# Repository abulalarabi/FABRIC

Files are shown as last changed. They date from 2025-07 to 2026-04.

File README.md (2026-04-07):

# **FABRIC**: `FA`bricating `B`odily-Expressive `R`obots for `I`nclusive and Low-`C`ost Design

## Abstract
Sign language is a vital visual-manual communication method for individuals with hearing impairments, yet current robotic systems remain expensive and technically inaccessible for embodied interaction. We present **FABRIC**, a low-cost, end-to-end toolkit that enables users to 3D print expressive robots and program bodily language through learning-from-demonstration. FABRIC supports upper-torso motion replication using video input and offers an intuitive visual programming interface, lowering barriers to designing embodied, communicative robots for diverse applications.

<p align="center">
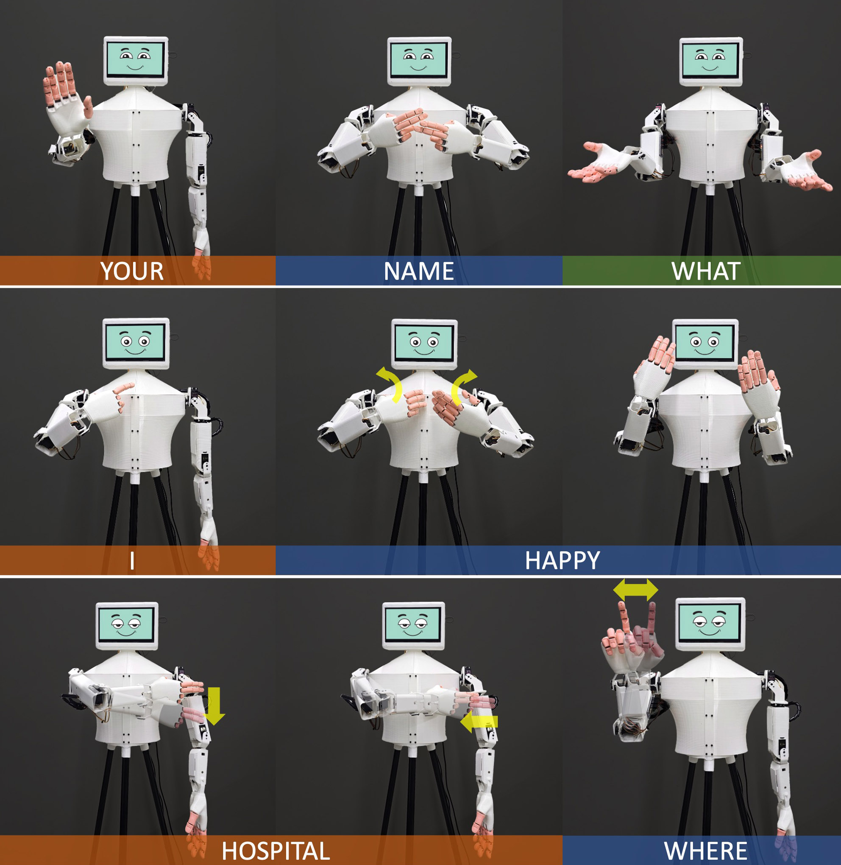
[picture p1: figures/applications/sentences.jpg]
  
</p>

## Paper Citation
```
@INPROCEEDINGS{11247443,
  author={Arabi, Abul Al and Kim, Jeeeun},
  booktitle={2025 IEEE/RSJ International Conference on Intelligent Robots and Systems (IROS)}, 
  title={FABRIC: FAbricating Bodily-Expressive Robots for Inclusive and Low-Cost Design}, 
  year={2025},
  volume={},
  number={},
  pages={1139-1146},
  keywords={Humanoid robot, Sign language robot, 3D Printing, Pose Estimation, Learningfromdemonstration},
  doi={10.1109/IROS60139.2025.11247443}}
```

## System Overview

<p align="center">
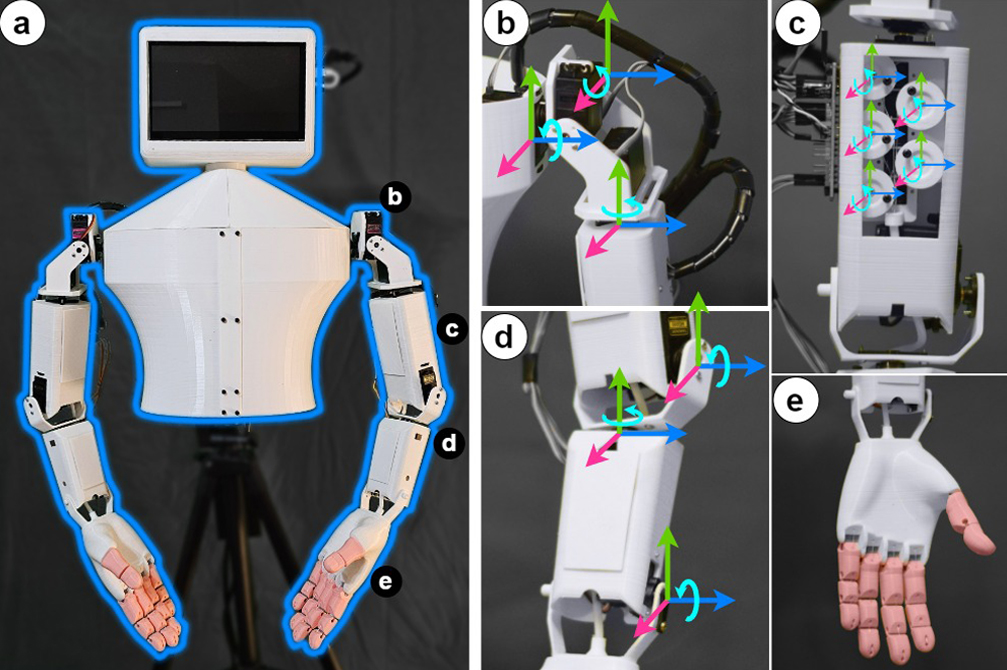
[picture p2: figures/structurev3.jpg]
  
</p>

Components of the FABRIC robot:  
(a) Assembled FABRIC unit  
(b) Shoulder joints  
(c) Finger movement servos mounted inside the upper arm  
(d) Elbow and wrist joint  
(e) Robotic hand

## Design Files
<table>
  <tr>
    <td align="center">
      <a href="design_files/body">
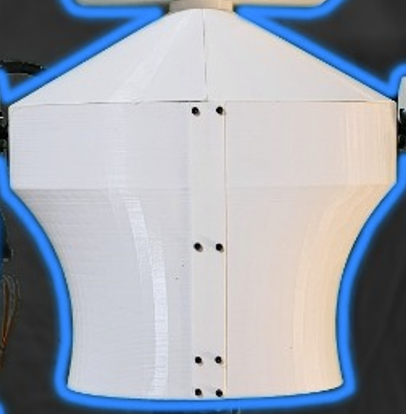
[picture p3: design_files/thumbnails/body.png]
        <br/>
        <sub><b>Body</b></sub>
      </a>
    </td>
    <td align="center">
      <a href="design_files/elbow">
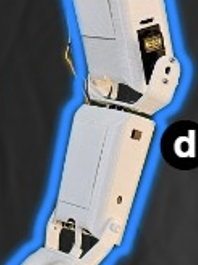
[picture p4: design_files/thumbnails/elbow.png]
        <br/>
        <sub><b>Elbow</b></sub>
      </a>
    </td>
    <td align="center">
      <a href="design_files/head">
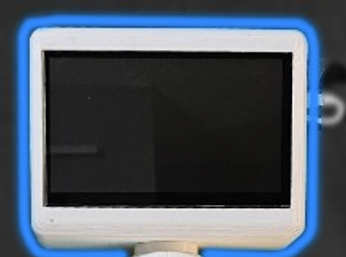
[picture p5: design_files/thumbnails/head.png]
        <br/>
        <sub><b>Head</b></sub>
      </a>
    </td>
    <td align="center">
      <a href="design_files/shoulder">
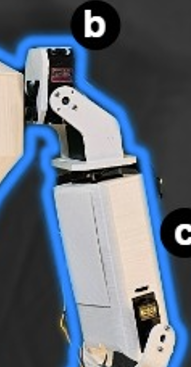
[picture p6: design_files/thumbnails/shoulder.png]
        <br/>
        <sub><b>Shoulder</b></sub>
      </a>
    </td>
  </tr>
  <tr>
    <td align="center">
      <a href="design_files/wrist+hand">
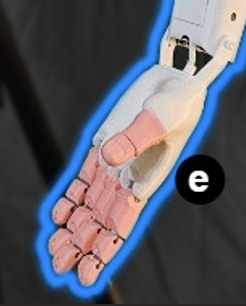
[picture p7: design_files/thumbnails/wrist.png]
        <br/>
        <sub><b>Wrist + Hand</b></sub>
      </a>
    </td>
    <td align="center">
      <a href="design_files/rivets">
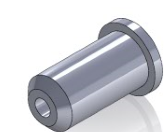
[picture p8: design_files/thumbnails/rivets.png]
        <br/>
        <sub><b>Rivets</b></sub>
      </a>
    </td>
    <td align="center">
      <a href="design_files/stand">
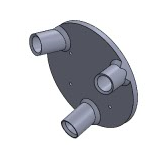
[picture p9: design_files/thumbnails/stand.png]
        <br/>
        <sub><b>Stand</b></sub>
      </a>
    </td>
    <td></td>
  </tr>
</table>

## Firmware
<a href="firmware">
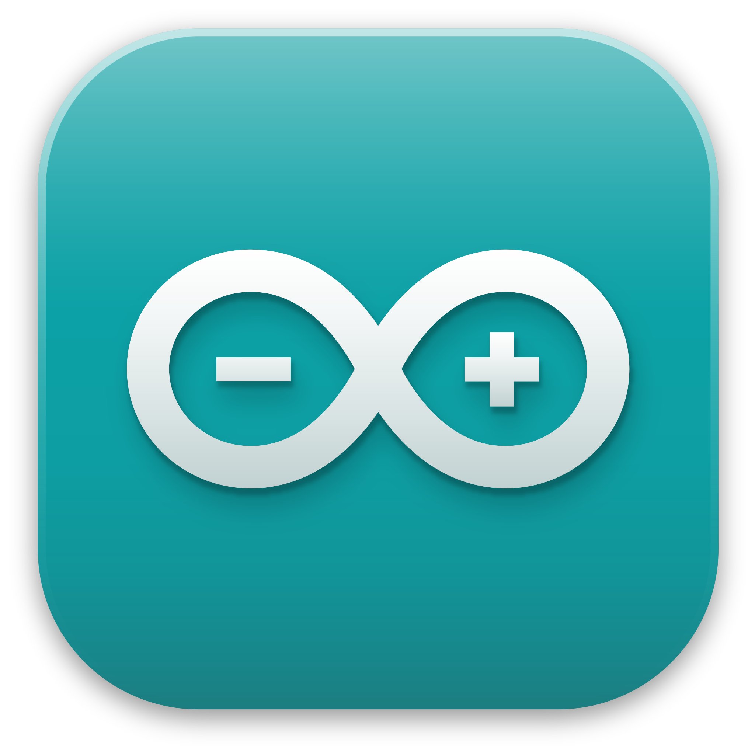
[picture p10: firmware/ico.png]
  <br/>
  <sub><b>Arduino Firmware of ESP32 (UART Version)</b></sub>
</a>

## Frontend + Backend
Will be updated soon.

## BoM and Component List

| Component | Quantity | URL |
|---|---|-----|
| ESP32 microcontroller | 1 | [Link](https://www.amazon.com/s?k=ESP32+microcontroller) |
| PCA9685 Servo Driver | 2 | [Link](https://www.amazon.com/s?k=PCA9685+Servo+Driver+module) |
| LM2596S DC-DC Converter | 1 | [Link](https://www.amazon.com/s?k=LM2596S+DC-DC+Converter) |
| MG996R Servos (arm) | 8 | [Link](https://www.amazon.com/s?k=MG996R+servo+motor) |
| SG90 Servos (finger/wrist) | 14 | [Link](https://www.amazon.com/s?k=SG90+mini+servo+motor) |
| PLA Filament (~1.5 kg) | ~1.5 kg | [Link](https://www.amazon.com/s?k=PLA+1.75mm+3D+printer+filament) |
| TPU Filament (~0.25 kg) | ~0.25 kg | [Link](https://www.amazon.com/s?k=TPU+1.75mm+flexible+filament) |
| PTFE Tube | 1 meter | [Link](https://www.amazon.com/s?k=PTFE+tube+1.75mm) |
| Power Adapter (12V 10A) | 1 | [Link](https://www.amazon.com/s?k=12V+10A+DC+power+adapter) |
| Display (7" Raspberry Pi LCD) | 1 | [Link](https://www.amazon.com/s?k=7+inch+Raspberry+Pi+LCD+touch+screen) |
| Jumper Wires, Headers | — | [Link](https://www.amazon.com/s?k=jumper+wires+male+to+female+kit) |
| Nylon String (Cables) | — | [Link](https://www.amazon.com/s?k=nylon+string+for+robotics) |
| Superglue | — | [Link](https://www.amazon.com/s?k=superglue) |
| Screws, zip ties | — | [Link](https://www.amazon.com/s?k=M3+screws+zip+ties+kit) |

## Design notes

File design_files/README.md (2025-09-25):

#### Hand and Hinges
* Scale everything to 80%
* Print hinges only with TPU -> 5~10% infill
* Print everything else with PLA
* 14 Hinges are required for one hand.
* No support required for palm.
* Use support material for fingers

#### Wrist and Pulleys
* Print everything with PLA.
* Use 0.1mm or 0.15mm layer height for the pulleys.
* Requires 5 pulleys for each hand.

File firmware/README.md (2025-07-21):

## 📦 Requirements

### 🧠 Hardware
- ESP32 board
- 2x PCA9685 16-channel Servo Drivers

### 🛠️ Libraries
Install the following libraries via the Arduino Library Manager:
- `Adafruit PWM Servo Driver Library`

## ⚙️ Wiring

Make sure the PCA9685 drivers are connected via I2C:
- Right driver: I2C address `0x40`
- Left driver: I2C address `0x41`

Connect the ESP32 I2C pins (as defined in the code):
- `SDA` → GPIO 8
- `SCL` → GPIO 9

## 🚀 Upload and Run

1. Open the sketch in **Arduino IDE**.
2. Select the correct **Board** (e.g., ESP32 Dev Module) and **Port**.
3. Install all required libraries.
4. Upload the sketch to your ESP32.
5. Open the **Serial Monitor** with baud rate `115200`.

## 🧪 Usage

Control the servo poses by sending formatted commands over Serial:

### ▶️ Commands Format
Command follows CSV format. Each command must be followed by **newline (`\n`)**.

- Update left servo target pose:
l:90,90,90,90,90,90,90,90,90,90,90

- Update right servo target pose:
r:45,45,45,45,45,45,45,45,45,45,45

- Execute motion:
e

This moves both left and right servos to their updated target poses.

### 💡 Notes
- Values must be **11 comma-separated integers** representing angles from `0` to `180`.
- Angles will be mapped to the correct PWM range using `sermin` and `sermax`.

## 🛠️ Functions Overview

| Function | Purpose |
|---|---|
| `initPose()` | Sets all servos to initial pose |
| `moveTo()` | Moves right servos smoothly to a new pose |
| `moveToL()` | Moves left servos smoothly to a new pose |
| `moveBoth()` | Moves both left and right servos together |
| `alphabet()` | Moves a subset of right servos (e.g., finger group) |
| `parseAndStore()` | Parses incoming serial data and stores pose |

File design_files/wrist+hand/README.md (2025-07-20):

### Palm and Finger
Download the flexihand model from Thingiverse: [Thingiverse: thing 242639](https://www.thingiverse.com/thing:242639)

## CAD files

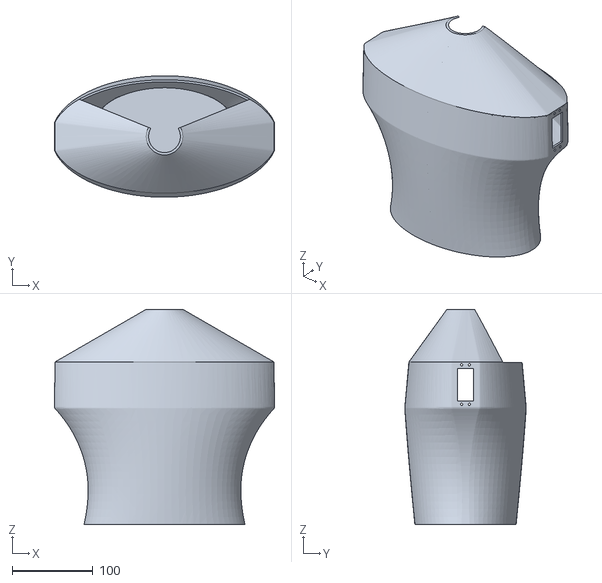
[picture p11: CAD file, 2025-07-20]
design_files/body/full_body.stl
271.7 x 150.0 x 266.0

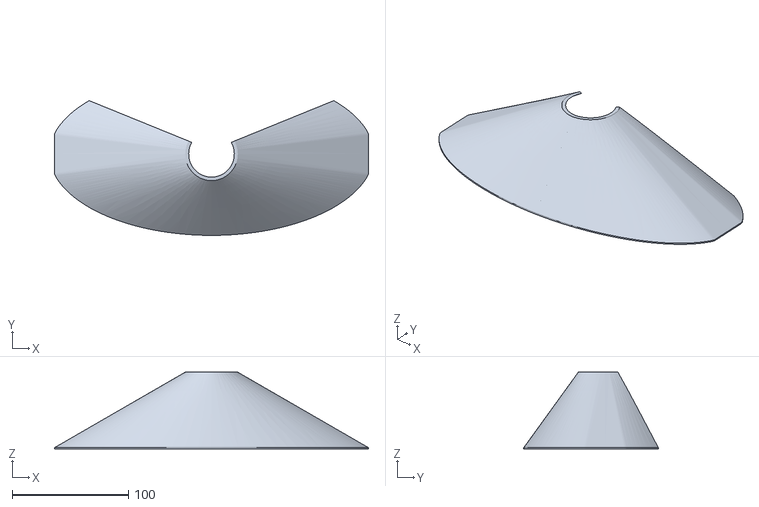
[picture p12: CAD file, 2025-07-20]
design_files/body/neck.STL
270.4 x 116.1 x 66.0

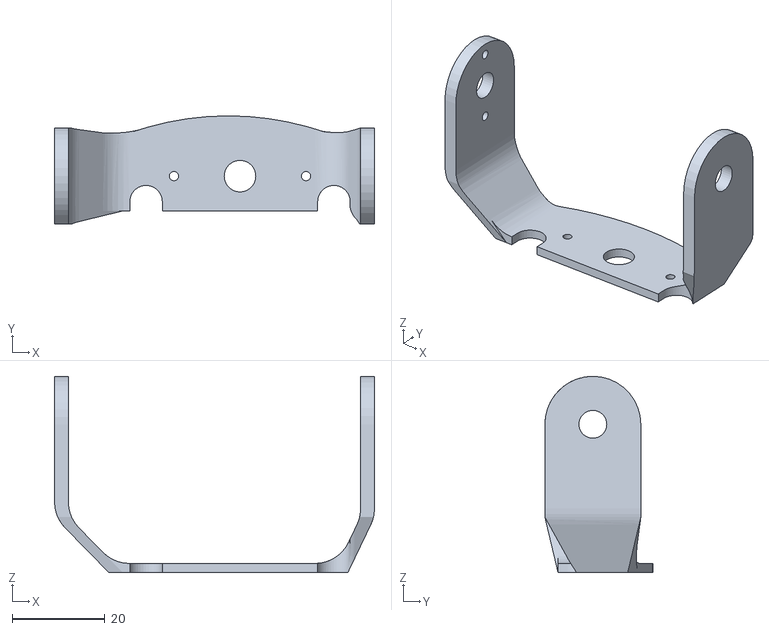
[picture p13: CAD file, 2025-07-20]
design_files/elbow/elbow_joint _v3.STL
69.0 x 23.4 x 42.4

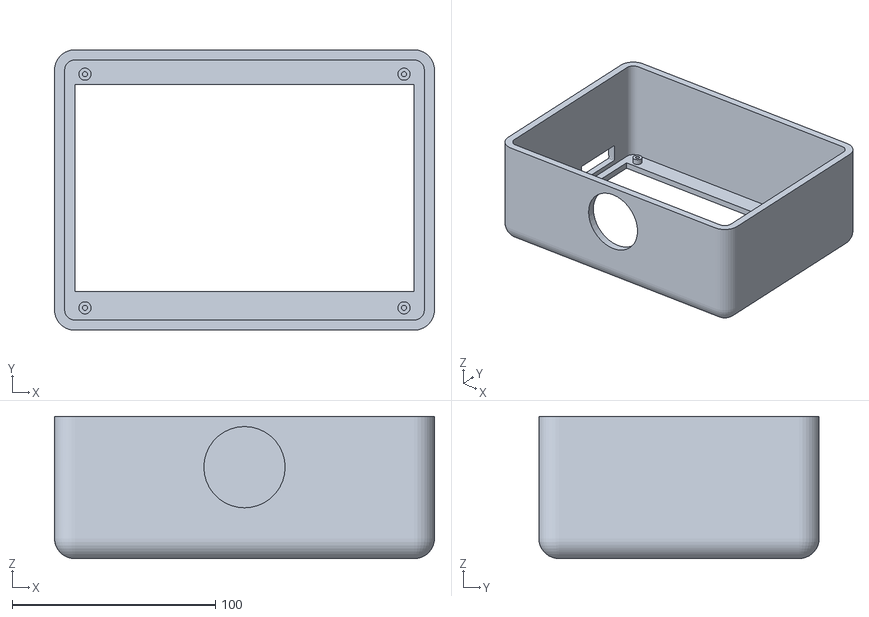
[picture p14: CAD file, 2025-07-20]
design_files/head/Display Frame.STL
187.0 x 138.0 x 70.0

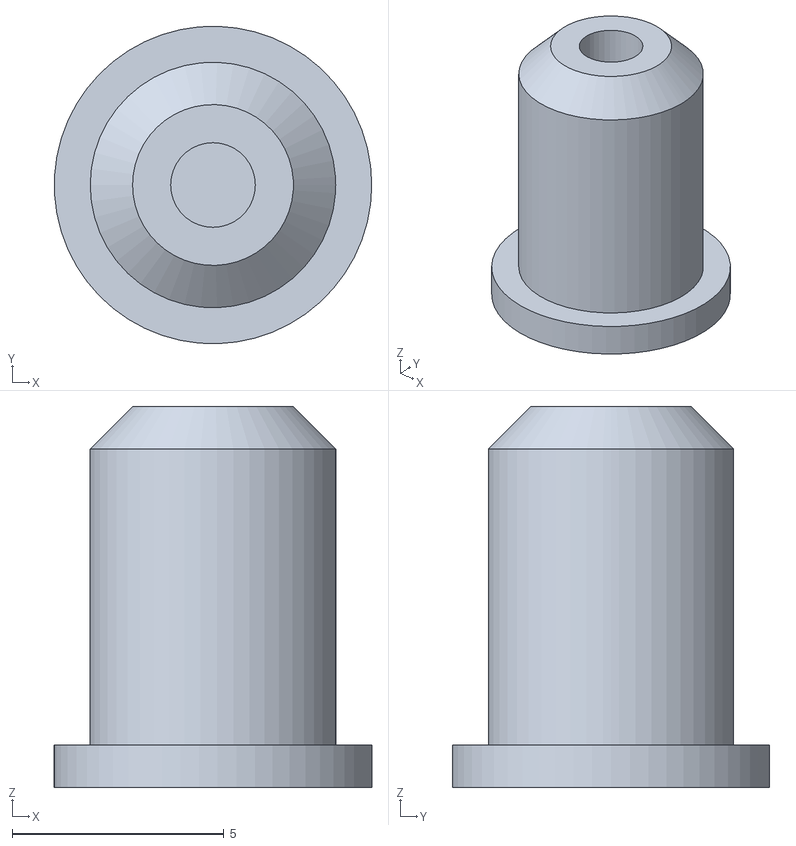
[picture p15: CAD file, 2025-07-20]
design_files/rivets/rivets.STL
7.50 x 7.50 x 9.00

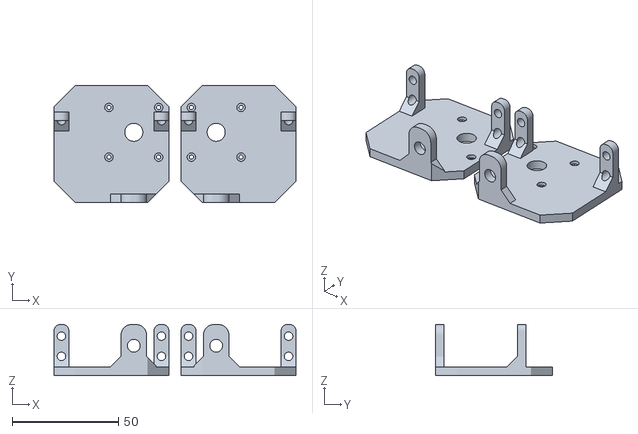
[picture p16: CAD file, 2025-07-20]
design_files/shoulder/servo_mount1.stl
113.7 x 55.0 x 24.0

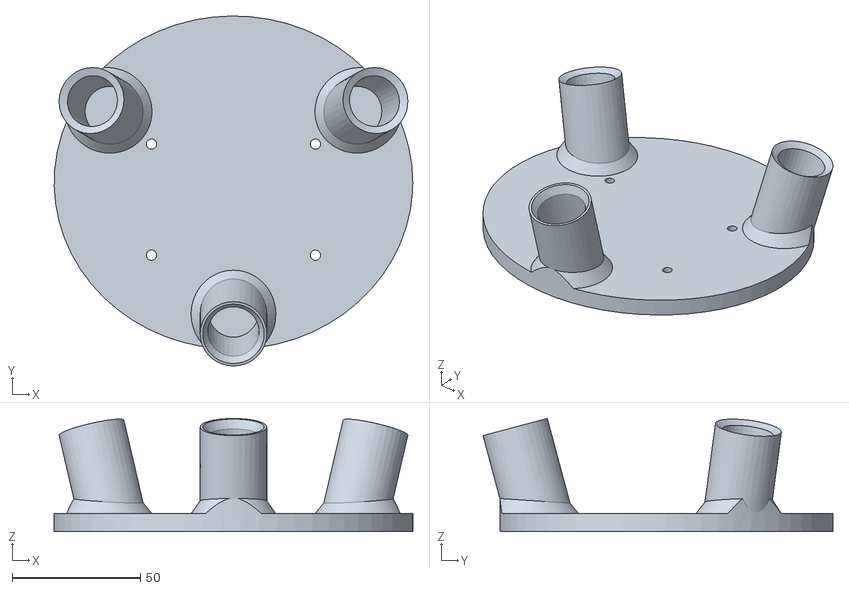
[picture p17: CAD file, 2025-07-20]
design_files/stand/stand_mount.STL
140.0 x 136.6 x 44.2

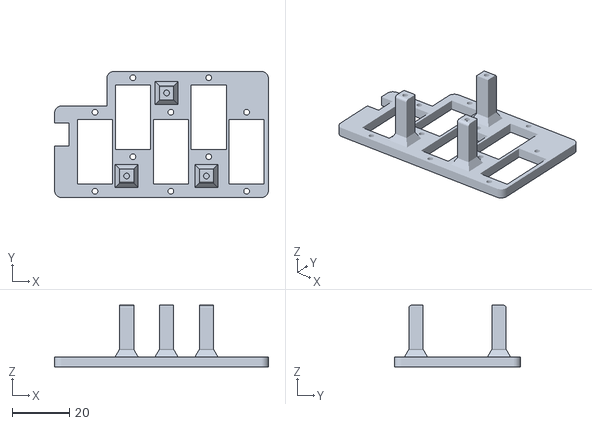
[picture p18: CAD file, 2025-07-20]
design_files/wrist+hand/servo_mount.STL
74.5 x 43.9 x 21.5

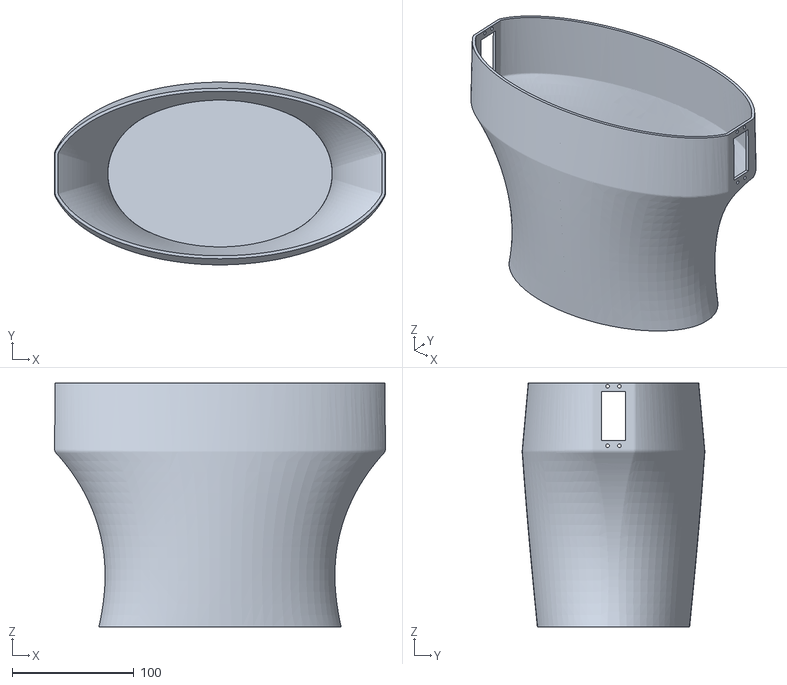
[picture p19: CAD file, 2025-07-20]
design_files/body/chest.STL
271.7 x 150.0 x 200.0

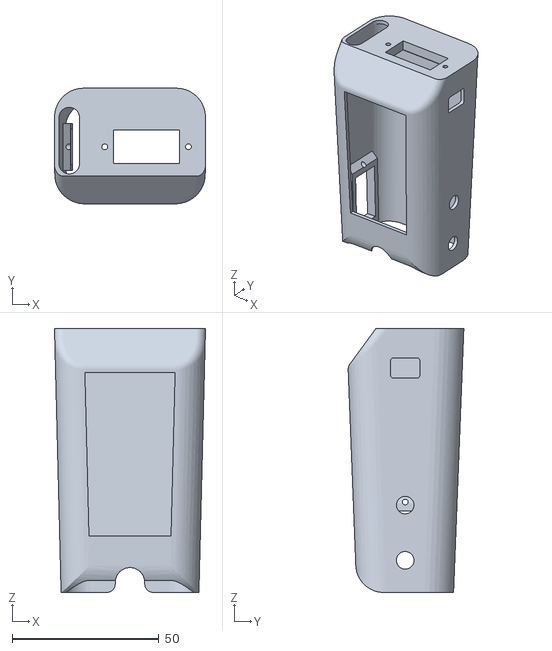
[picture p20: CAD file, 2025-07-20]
design_files/elbow/forearm.STL
51.5 x 39.5 x 90.0

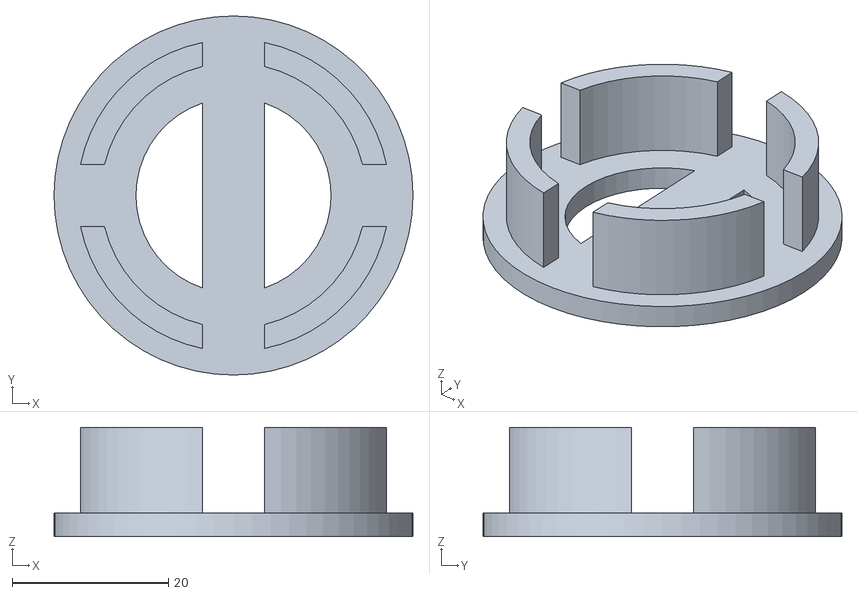
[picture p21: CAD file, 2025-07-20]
design_files/head/snap.STL
46.0 x 46.0 x 14.0

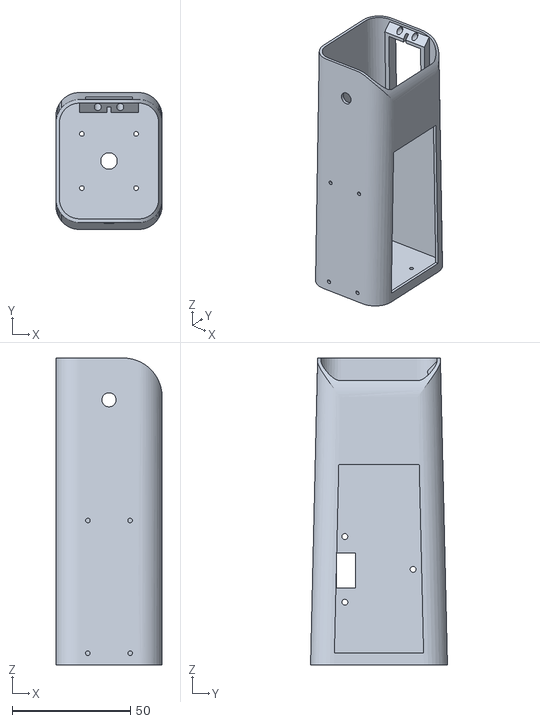
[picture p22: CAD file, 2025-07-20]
design_files/shoulder/bicep.STL
45.0 x 58.0 x 130.0

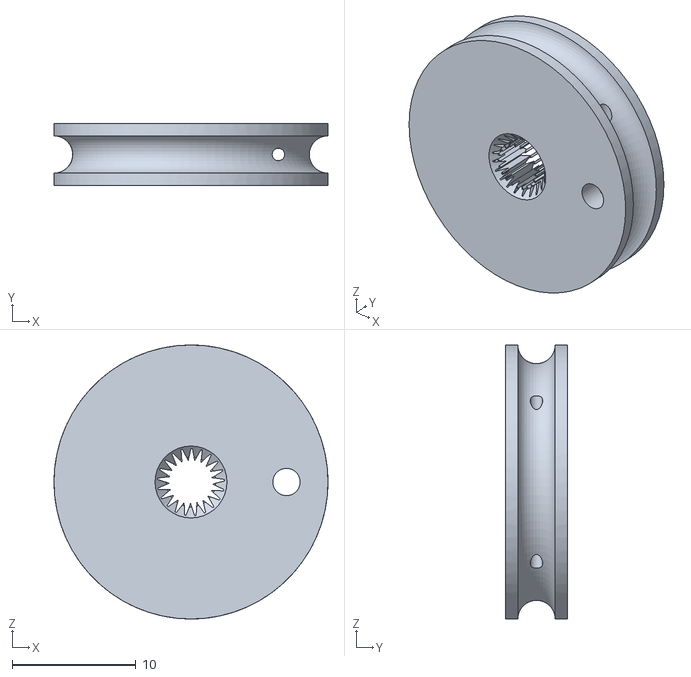
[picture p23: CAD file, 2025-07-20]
design_files/wrist+hand/pulley.STL
22.1 x 5.00 x 22.1

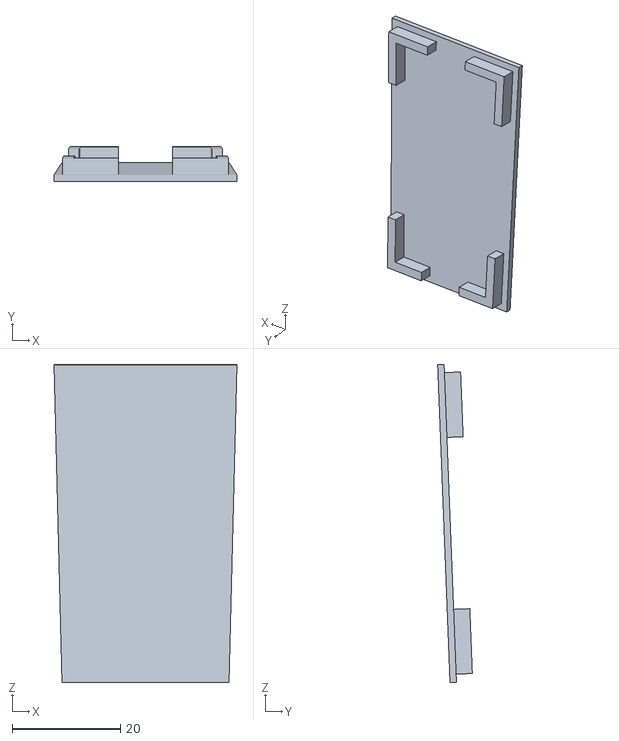
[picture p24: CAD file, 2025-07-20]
design_files/elbow/forearm_cover.STL
33.8 x 6.42 x 58.8

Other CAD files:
design_files/head/neckJoint.STL
design_files/shoulder/bicep_cover.STL
design_files/wrist+hand/wrist_joint.STL
design_files/shoulder/joint+servo_mount2.stl

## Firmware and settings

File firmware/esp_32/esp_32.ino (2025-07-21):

// UART Version

//#include <WiFiUdp.h>
#include <WiFi.h>
#include <Wire.h>
#include <Adafruit_PWMServoDriver.h>
// #include <PubSubClient.h>


Adafruit_PWMServoDriver right = Adafruit_PWMServoDriver(0x40);
Adafruit_PWMServoDriver left = Adafruit_PWMServoDriver(0x41);


#define SERVOMIN 80   // This is the 'minimum' pulse length count (out of 4096)
#define SERVOMAX 470  // This is the 'maximum' pulse length count (out of 4096)

#define SERVO_FREQ 50  // Analog servos run at ~50 Hz updates

// Calibrate the servo max-min based on your servo
int sermin[11] = { 140, 90, 140, 110, 470, 470, 470, 85, 85, 75, 75 };
int sermax[11] = { 500, 490, 500, 490, 85, 85, 85, 470, 470, 480, 480 };

float rightInitPose[11] = { 0, 85, 90, 0, 0, 0, 0, 0, 0, 180, 90 };
float leftInitPose[11];
float rightPose[11];
float leftPose[11];


int angle(float a, int i) {
  int pwmValue = map(a, 0, 180, sermin[i], sermax[i]);
  return pwmValue;
}

void initPose() {
  for (int i = 0; i < 11; i++) {
    rightPose[i] = rightInitPose[i];
    leftInitPose[i] = 180 - rightInitPose[i];
    leftPose[i] = leftInitPose[i];
    right.setPWM(i, 0, angle(rightPose[i], i));
    delay(5);
    left.setPWM(i, 0, angle(leftPose[i], i));
  }
  for (int i = 0; i < 11; i++){
    Serial.print(leftPose[i]);
    Serial.print(",");
  }
  Serial.println();
}

void resetPose() {
  for (int i = 0; i < 11; i++) {
    right.setPWM(i, 0, 0);
    left.setPWM(i, 0, 0);
  }
}

void setup() {
  Serial.begin(115200);

  Wire.begin(8, 9);
  right.begin();
  right.setOscillatorFrequency(26000000);
  right.setPWMFreq(SERVO_FREQ);  // Analog servos run at ~50 Hz updates

  left.begin();
  left.setOscillatorFrequency(26000000);
  left.setPWMFreq(SERVO_FREQ);  // Analog servos run at ~50 Hz updates


  delay(10);
  initPose();
}

int slowDown = 5; // higher = slower

void moveTo(float finalPose[11]) {
  float rightInc[11];
  float steps = 120;
  for (int i = 0; i < 11; i++) {
    rightInc[i] = (finalPose[i] - rightPose[i]) / steps;
  }
  for (float i = 0; i <= steps; i++) {
    for (int j = 0; j < 11; j++) {
      rightPose[j] = rightPose[j] + rightInc[j];
      right.setPWM(j, 0, angle(rightPose[j], j));
    }
    delay(slowDown);
  }
}

void moveToL(float finalPose[11]) {
  float leftInc[11];
  float steps = 120;
  for (int i = 0; i < 11; i++) {
    leftInc[i] = (finalPose[i] - leftPose[i]) / steps;
  }
  for (float i = 0; i <= steps; i++) {
    for (int j = 0; j < 11; j++) {
      leftPose[j] = leftPose[j] + leftInc[j];
      left.setPWM(j, 0, angle(leftPose[j], j));
    }
    delay(slowDown);
  }
}

void moveBoth(float finalPose[11], float finalPosel[11]) {
  float leftInc[11];
  float rightInc[11];

  float steps = 80;
  for (int i = 0; i < 11; i++) {
    leftInc[i] = (finalPosel[i] - leftPose[i]) / steps;
    rightInc[i] = (finalPose[i] - rightPose[i]) / steps;
  }
  for (float i = 0; i <= steps; i++) {
    for (int j = 0; j < 11; j++) {

      rightPose[j] = rightPose[j] + rightInc[j];
      right.setPWM(j, 0, angle(rightPose[j], j));
      delay(2);
      leftPose[j] = leftPose[j] + leftInc[j];
      left.setPWM(j, 0, angle(leftPose[j], j));
    }
    delay(slowDown);
  }
}


void alphabet(float alphPose[5]) {
  float rightInc[5];
  float steps = 120;
  for (int i = 0; i < 5; i++) {
    rightInc[i] = (alphPose[i] - rightPose[4 + i]) / steps;
  }

  for (float i = 0; i <= steps; i++) {
    for (int j = 0; j < 5; j++) {
      rightPose[4 + j] = rightPose[4 + j] + rightInc[j];
      right.setPWM(4 + j, 0, angle(rightPose[4 + j], 4 + j));
    }
    delay(slowDown);
  }
}


const byte MAX_VALUES = 11;

float leftArray[MAX_VALUES] = { 0 };
float rightArray[MAX_VALUES] = { 0 };

bool leftUpdated = false;
bool rightUpdated = false;

String inputString = "";
bool inputComplete = false;
//inputString.reserve(100);

void loop() {
  // Read serial input
  while (Serial.available()) {
    char inChar = (char)Serial.read();
    if (inChar == '\n' || inChar == '\r') {
      inputComplete = true;
    } else {
      inputString += inChar;
    }
  }

  if (inputComplete) {
    
    inputComplete = false;
    if (inputString[0]=='e') {
      Serial.println("Executing...");
      moveBoth(rightArray,leftArray);
      
      leftUpdated = false;   // Reset flags
      rightUpdated = false;
    }
    else{
      parseAndStore(inputString);
    }
    inputString = "";
  }
}

void parseAndStore(String data) {
  if (data.length() < 2 || data.charAt(1) != ':') {
    Serial.println("Invalid format. Use l: or r:");
    return;
  }

  char target = data.charAt(0);
  String csvData = data.substring(2);

  int tempArray[MAX_VALUES] = {0};
  int index = 0;
  int lastIndex = 0;
  int commaIndex;

  while ((commaIndex = csvData.indexOf(',', lastIndex)) != -1 && index < MAX_VALUES) {
    tempArray[index++] = csvData.substring(lastIndex, commaIndex).toInt();
    lastIndex = commaIndex + 1;
  }

  if (index < MAX_VALUES && lastIndex < csvData.length()) {
    tempArray[index] = csvData.substring(lastIndex).toInt();
  }

  if (target == 'l') {
    for (int i = 0; i < MAX_VALUES; i++) leftArray[i] = tempArray[i];
    leftUpdated = true;
    Serial.println("Left array updated:");
    printArray(leftArray);
  } else if (target == 'r') {
    for (int i = 0; i < MAX_VALUES; i++) rightArray[i] = tempArray[i];
    rightUpdated = true;
    Serial.println("Right array updated:");
    printArray(rightArray);
  } else {
    Serial.println("Unknown target. Use 'l' or 'r'");
  }
}

void printArray(float arr[]) {
  for (int i = 0; i < MAX_VALUES; i++) {
    Serial.print(arr[i]);
    if (i < MAX_VALUES - 1) Serial.print(", ");
  }
  Serial.println();
}
